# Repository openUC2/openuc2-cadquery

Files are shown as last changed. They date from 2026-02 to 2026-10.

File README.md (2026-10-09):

# openUC2 CadQuery Insert Generator (v4-style)

Programmatic generation of an **openUC2 cube insert** and **component cutouts** using **CadQuery**.

> **New: `uc2v4/` — exact parametric reconstructions of the molded V4 inserts.**
> Built from the Inventor master models (COM extraction, see
> [`extracted/README.md`](extracted/README.md)) and verified against the
> released STEP geometry:
>
> *Square-insert family* (`build_uc2v4.py`):
>
> - `uc2v4.build_master_insert()` → PRT - 2123 - MASLCK - V04 - B
>   (4 mm master-insert plate: springs, corner ribs, 82° cone opening,
>   8×45° nose grooves, self-mating screw pattern)
> - `uc2v4.build_lens_insert()` → PRT - 2027 - INSLEND43F-50 - V04
>   (17 mm lens insert: parametric `lens_diam`, pocket/seat/aperture,
>   2-turn pitch-1.7 clamping thread for the pre-screw ring)
>
> *Round-holder family* (`build_mirror_holder.py`):
>
> - `uc2v4.round_holder.build_base_holder()` → the reusable blank: the conic
>   disk whose 8 noses are the exact positives of the master insert's
>   grooves, so it seats on 45° indexing
> - `uc2v4.round_holder.build_mirror_holder()` → PRT - 2111 - MASINSMIRHOLUPP - C
>   (obround beam aperture + sandwich screw counterbores)
>
> ```bash
> uv run --with cadquery --with trimesh --with rtree --with scipy python build_uc2v4.py
> ```
> writes STEP/STL into `generated/` and prints the mesh-deviation report
> against `extracted/*.step`. Design write-up: [`DOCS-insert-v4-design.md`](DOCS-insert-v4-design.md).
> Both families are available to optikit-core as standalone T3 generators
> (`openuc2.tpl.square_insert_v4`, `openuc2.tpl.round_holder_v4`).

> **Automatic lens cartridges — `uc2v4/lens_cartridge.py`.**
> Give it a lens and a target pose measured from the cube centre; it snaps to
> the cube's notch grid (7 notches, 5.0 mm pitch, measured from
> `PRT - 1003 - CUBHLF111`), hands the residual offset and tilt to the printed
> parts, and writes the **front and back** round inserts that clamp the lens
> and drop into the molded master inserts:
>
> ```bash
> uv run --with cadquery python uc2v4/lens_cartridge.py --diameter 25.4 --thickness 3.5 --r1 51.5 --r2 -51.5 -x 3.0 -y -2.0 -z 6.1 --extension-front 1.5 --extension-back 1.5
> ```
>
> Each run also writes a `*_layout.png` schematic of the cube, the notch grid,
> the molded/printed sandwich and the lens, and engraves an identifying label
> on each outward face.
>
> `check_lens_cartridge.py` verifies a generated pair (one solid per half, no
> overlap, zero lens-to-holder collision, snug pocket, pose reproduced,
> envelope respected, **and the cone rings facing the joint** — the halves are
> not symmetric and a mirrored build passes every other check).

> **Beamsplitter / fluorescence-filter cubes — `uc2v4/beamsplitter_insert.py`.**
> A printable two-part **clamshell** (modelled on PRT-2074 / PRT-2075) that
> carries an **excitation filter**, an **emission filter** and a **45° dichroic**
> through one cube. Each optic is independently a round disc or a rectangular
> plate, with its own thickness; the excitation reflects off the dichroic to
> the sample port, the emission passes straight through:
>
> ```bash
> uv run --with cadquery python uc2v4/beamsplitter_insert.py            # the reference set
> uc2cad beamsplitter --exc-diam 25.4 --exc-thick 4 \
>                     --emi-diam 25.4 --emi-thick 4 \
>                     --dic-w 25 --dic-thick 1 --beam 18                 # or via the CLI
> ```
>
> It writes the **lower and upper** halves (STEP + STL) plus the plan JSON.
> `check_inserts.py` verifies each build (one solid per half, no overlap, every
> optic drops into its seat and lifts out of the split plane, all beam legs
> bored, pins registered). Design write-up:
> [`DOCS-beamsplitter-insert.md`](DOCS-beamsplitter-insert.md).

> **Optical-module plates — `uc2v4/opm_plates.py`.** The two 5 mm aluminium
> plates that sandwich an OPM, for **any layout**: a core rectangle such as
> `3x8` or `3x3` plus extra puzzle units on any side (`3x8+1x1@-1,0`), or a
> layout drawn as ASCII art. Built from the master `MAS - 1003 - Base plates
> Al - V04` and the released pairs (PRT-1051/1052 FLIM 488, 1053/1054, 1026/1027,
> 1047/1048): 50.0 × 50.1 mm cells with four M3 holes and a Ø38 pocket each,
> R1.5/R10.2 corners, the outward-face chamfer, tie rods at the core's corners
> (every ≤ 3 cells along long edges — the released rule), counterbores on the
> top, sleeve-nut U-slot recesses underneath, optional M37×0.5 ports:
>
> ```bash
> uv run --with cadquery --with matplotlib python build_opm_plates.py   # edit the layouts in there
> uc2cad plates --layout 3x8+1x1@-1,0 --port 1,7                       # or via the CLI
> ```
>
> Each module writes the top and base plate (STEP + STL), the assembled stack,
> a plan JSON (cells, tie rods, ports, hardware such as `8 x ISO 4762 M3x115`)
> and a layout diagram. `check_opm_plates.py` reproduces the tie rods of all five
> released plate families and matches PRT-1052 feature for feature (all 149
> cylindrical features, same 203 faces, volume −0.012 %). Design write-up:
> [`DOCS-opm-plates.md`](DOCS-opm-plates.md).

> **dvOPM camera, launch and sample parts — `uc2v4/opm_camera_adapter.py`,
> `uc2v4/opm_launch_holder.py`, `uc2v4/opm_sample_holder.py`.** The printed parts of the
> direct-view OPM on a 5x4 plate. Its detection stays in openUC2 cubes: the fold mirror and the
> reversed telecentric lens use the CAD-new modules ASS-2020 and ASS-3011 turned inside their
> cubes, and the only new detection part is the **camera adapter** — a double base-holder disc
> captured between a MASLCK and a MASINS like any printed round insert, with a bracket, a spine
> and a 4 mm plate that holds the Alvium bare board at the sensor tilt (50 deg) in the cube; the
> sensor looks through a window, four M2 hold the board from behind. The **launch holder**
> carries the RMS-threaded 4x objective, the LJ1878L1 cylinder lens (side slot + sliding key)
> and the f = 8 fibre collimator (side-slid fork clip); the arc-rail bracket's two concentric
> slots pivot it about the sheet's entry point, and the bracket hangs from the launch stage's
> slide when the slide stands above the holder. The **sample arm** is one flat slab on the
> sample stage's slide with the dish ring. Every dimension comes from the layout model in
> `openuc2-opmsimulator/opm_layout.py` (`opm_layout.json`):
>
> ```bash
> uc2cad opm-camera ../openuc2-opmsimulator/opm_layout.json      # camera adapter -> generated/opm_detection
> uc2cad opm-launch ../openuc2-opmsimulator/opm_layout.json      # holder, key, clip, bracket -> generated/opm_launch
> uc2cad opm-sample ../openuc2-opmsimulator/opm_layout.json      # sample arm + dish -> generated/opm_launch
> uv run --with cadquery python check_opm_launch_holder.py ../openuc2-opmsimulator/opm_layout.json
> ```
>
> The camera cube as built (adapter, inserts, board) is checked in openuc2-opmsimulator
> (`check_opm_detection_cubes.py`); `check_opm_launch_holder.py` verifies the thread, the seats
> and retainers, the clamp screws and that every medium's screw position lies in the bracket's
> slots. The plan JSON's `params` block also drives
> `openuc2-opmsimulator/build_opm_holder_ipt.py`, which rebuilds the launch holder as a **native
> parametric Inventor part** (35 user parameters, coil-cut RMS thread);
> `check_opm_holder_native.py <its .stp> generated/opm_launch` samples that part against the
> CadQuery reference. The beam-path solids (`generated/opm_launch/opm_beam_*.step`) come from
> `openuc2-opmsimulator/opm_beam_solids.py`. `uc2v4/opm_detection_holder.py` and
> `check_opm_detection_holder.py` are the superseded one-piece detection holder (2026-10-02).
> Pipeline write-up: `openuc2-opmsimulator/OPM_CAD_README.md`.

> **Holders for turning an optical design into cubes (2026-10-03).** The geometry behind
> optikit-core's generators (`generators/*_v4.py` there), each with a `plan_*` that checks
> without building and a `check_*.py` here that verifies the parts against what they hold:
>
> | module | holds | check |
> |---|---|---|
> | `round_clamp.py` | a cylinder body up to Ø34 mm (laser module, fibre collimator, tube) between two master inserts, one set screw | `check_round_clamp.py` |
> | `kinematic_adapter.py` | any round or rectangular optic in the ½-inch kinematic mount ZJB-0.5-3, on a plate or a wedge | `check_kinematic_adapter.py` |
> | `bolt_cradle.py` | a device by the holes in one face: an insert across the beam, or a pedestal on a plate | `check_bolt_cradle.py` |
> | `focus_cartridge.py` | a lens in a barrel that slides ±1 mm in a round clamp, set-screw lock | `check_focus_cartridge.py` |
> | `off_grid_plate.py` | a plate in the puzzle layer over a list of cells: kinematic pedestal, saddle, cradle, lens wall; docking poses | `check_off_grid_plate.py` |
> | `cube_pocket.py` | a beamsplitter cube at the centre of a cell, in the fluorescence clamshell | `check_cube_pocket.py` |
> | `slide_slot.py` | a microscope slide across the beam, stop, coverslip pocket | `check_slide_slot.py` |
> | `sample_vessel.py` | a vial or a cuvette upright across the beam, windows, light-tight cap | `check_sample_vessel.py` |
> | `cell_cover.py` | a light-tight cover over a list of cells with an interlock switch housing | `check_cell_cover.py` |
>
> `lens_cartridge.snap_joint` places every master-insert pair, and its joint plane stays within
> ±13 mm of the cube centre (`CubeInterface.joint_limit_mm`; further out the outer insert sits
> on the cube's end frames). optikit-core pins v0.6.0 and needs a new tag for these.

> **FRAME objective supports — `uc2v4/frame_objective_support.py` (2026-10-09).** The printed
> part between the FRAME's kinematic objective sled (FR110-0401) and an objective, as the
> `FRAME - 0402 / 0408 - Support objective` parts are built (measured on them): a 5.2 mm flange
> with two M2.5 lugs, a Ø25.4 boss up to the objective's shoulder, the objective's thread printed
> in the top of the bore. Thread (RMS, M25x0.75, M26x0.706, M27x0.75, C-mount, M<Ø>x<pitch>),
> height and label are parameters; `parfocal_heights` gives one height per slot so all
> objectives focus in one plane (61.4 mm above the sled for two PF-45 objectives, the CAD's 16.4
> mm supports). RMS fits as in the CAD; M25x0.75 and C-mount get screw pockets in a Ø29+ boss
> (0.6-0.8 mm wall to the pockets); M26 and wider are refused — their bore reaches the sled's
> M2.5 screws at r 16 mm, so they need a sled with the screws further out. `check_frame_objective_support.py [--cad <FRAME-0402.stp> 16.4]` checks the rules and
> samples a CAD part against the model. optikit-core's `generators/frame_objective_support.py`
> wraps it for the FRAME wizard (needs this release, v0.8.0).

> **Browser wizard — `uc2cad wizard`.** No command line needed: run it and a
> page opens where you enter the numbers for a **lens holder** or a
> **beamsplitter cube**, or click an **OPM plate layout** together on a grid,
> and download a ZIP of the files. It uses only the Python standard library
> (plus CadQuery), so it runs anywhere the generators do:
>
> ```bash
> uv run --with cadquery python -m uc2v4.wizard        # opens http://127.0.0.1:8137/
> ```

> The scripts below predate the extraction and approximate the outline from
> drawings — still useful as simple starting points, but `uc2v4/` is the
> measured reference.

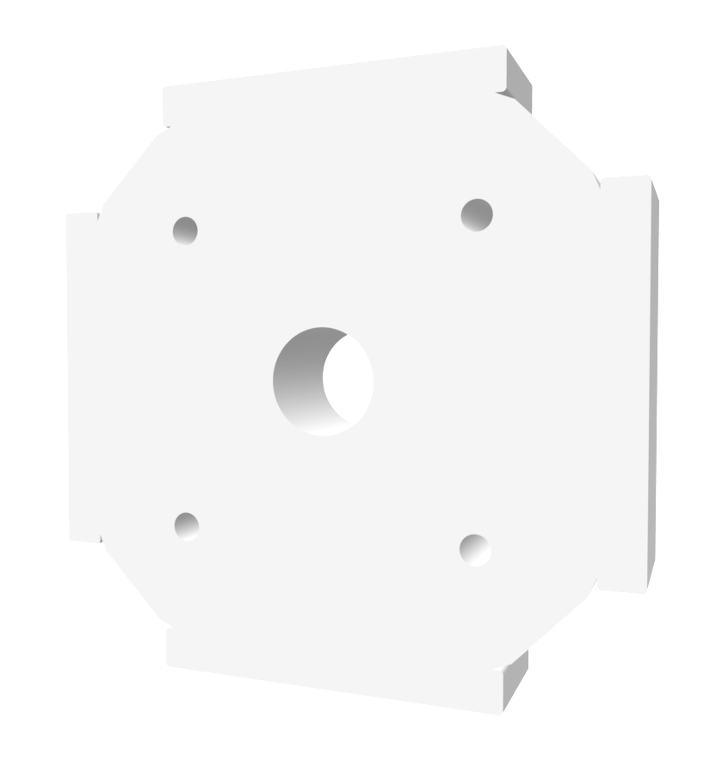
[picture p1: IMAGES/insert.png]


*Python-generated generic insert that can e.g. host a lens or something*

Goal:
- Create a reusable **insert “blank”** (outer geometry + optional tabs/wings + threaded holes).
- Create separate **component STEP cutters** (lens pockets, motor clearances, etc.).
- **Import any STEP cutter**, apply an **affine transform**, and **subtract** it from the insert to produce a printable/custom holder.

Coordinate system:
- **Optical axis = Z-axis**
- Optical axis passes through **(0, 0)** in the XY-plane
- All shapes are built around the origin by default

## Files

### 1) `uc2_component_cut_step.py`
Creates a **negative volume** (“cutter”) as a STEP file.

Typical use:
- Generate a lens pocket as a cylinder + optional seat + optional set-screw holes.
- Export as `component_cut.step` (and optionally `component_cut.stl`).

You can create multiple cutters, e.g.:
- `lens_25mm_cut.step`
- `motor_clearance_cut.step`
- `laser_mount_cut.step`

These STEP cutters are then consumed by the insert builder.

### 2) `uc2_insert_builder.py`
Creates the **insert body** and subtracts one or more imported STEP cutters.

What it generates:
- Outer insert outline (octagon-like profile from the technical drawing)
- Optional side tabs (or “wings” depending on the version you use)
- Optional center bore (or you do center bore via cutter STEP)
- Optional threaded/tapping holes
- Subtraction of imported cutters after applying affine transforms
- Exports `uc2_insert.step` and `uc2_insert.stl`

## Install

Create an environment and install CadQuery:

```bash
pip install cadquery
```

If your Python environment is already set up (e.g. `mambaforge`), install into that environment.

## Quick start

### Step 1: Create a cutter STEP (example lens pocket)

```bash
python uc2_component_cut_step.py
```

This writes:

* `component_cut.step`
* `component_cut.stl` (optional)

### Step 2: Build the insert and subtract the cutter

Edit `uc2_insert_builder.py` and add the cutter to `CUTTERS`, then run:

```bash
python uc2_insert_builder.py
```

This writes:

* `uc2_insert.step`
* `uc2_insert.stl`

## How cutters work

A cutter is any **solid STEP** you want to subtract from the insert.

Typical workflow:

1. Generate a cutter STEP in a dedicated script (preferred, reproducible)
2. Add it to `CUTTERS` list in `uc2_insert_builder.py`
3. Assign an affine transform for positioning/orientation
4. Boolean subtract (`insert.cut(cutter)`)

This supports:

* Lens holders (coaxial to optical axis)
* Motor pockets (offset + rotated)
* LED/laser holders
* Cable channels / clearance volumes
* Any imported CAD STEP solid

## Affine transforms

Each cutter can be positioned and rotated with:

* Translation: `tx, ty, tz` (mm)
* Rotation: `rx, ry, rz` (degrees, applied about origin, in order X → Y → Z)

Example: shift 2 mm in X, rotate 15° around optical axis:

```python
CUTTERS = [
    ("component_cut.step", Affine(tx=2.0, ty=0.0, tz=0.0, rx=0.0, ry=0.0, rz=15.0)),
]
```

Tip:

* If you want a lens centered on the optical axis, keep `(tx, ty) = (0, 0)`.

## Parameters you typically adjust

In `uc2_insert_builder.py`:

* `OUTER_HALF`, `SHOULDER_HALF` : insert outline
* `INSERT_THICKNESS`            : extrusion thickness
* `ADD_SIDE_TABS`, tab dimensions
* `ADD_THREAD_HOLES` and hole geometry
* `CUTTERS` list and each cutter transform

In `uc2_component_cut_step.py`:

* Lens diameter + clearance
* Seat diameter + depth
* Set screw count, diameter, radius

## License / contributions

This approach is meant to support openUC2’s open insert ecosystem:

* Generate inserts reproducibly
* Share scripts + parameters
* Allow others to remix and extend

If you create a useful cutter for a common component (lens size, motor, LED), publish it with:

* source script
* generated STEP
* a short usage snippet (recommended transform and parameters)

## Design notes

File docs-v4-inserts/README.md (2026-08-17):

# Documentation page: Module inserts (V4)

A user-facing page for
<https://docs.openuc2.com/dev/hw/module-inserts/v4/>, written for people
assembling openUC2 hardware rather than for people opening CAD.

## Contents

| file | what it is |
| --- | --- |
| `module-inserts-v4.md` | the page itself, Markdown with Docusaurus front matter |
| `img/*.png` | the figures it references |
| `make_figures.py` | regenerates figures 01–07 |

## Dropping it into the docs site

Copy `module-inserts-v4.md` to the page's location and `img/` alongside it.
The page uses relative image paths (`./img/01-overview.png`), which is what
Docusaurus expects when the images sit next to the Markdown file. If the site
keeps images in `static/img/` instead, adjust the seven paths accordingly.

## Regenerating the figures

```bash
uv run --with matplotlib python make_figures.py
```

Figures 01–07 are schematic matplotlib drawings — deliberately not to scale.
Small features (the teeth, the cone taper, the wall that traps a lens) are
exaggerated where that makes the point readable; the dimensions quoted in the
text are the real measured ones. Figure 08 is a render of an actually
generated pair of inserts, produced from the STLs that
`uc2v4/lens_cartridge.py` writes.

## Where the numbers come from

Everything quoted on the page was measured out of the Inventor originals via
the COM API rather than taken from drawings — see
[`../DOCS-insert-v4-design.md`](../DOCS-insert-v4-design.md) for the engineer-facing
version with the full derivation, and [`../extracted/README.md`](../extracted/README.md)
for the raw dumps.

Two statements on the page are *inferred* rather than directly measured, and
are worth confirming before the page goes public:

- that a sandwich is always **two** master inserts, one toothed and one
  smooth (this follows from the self-mating screw pattern and the assembly,
  but "both toothed" has not been ruled out);
- the exact phase of the tooth grid relative to the sandwich — the page only
  says the teeth are 5 mm apart, which is measured and safe, and deliberately
  avoids the finer claim.

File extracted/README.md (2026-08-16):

# Extracted ground truth (Inventor -> JSON/STEP)

Everything in this folder was pulled out of the original Autodesk Inventor
CAD through the COM automation interface by
[`PyInventor/inventor_part_probe.py`](../../PyInventor/inventor_part_probe.py):

```bash
python inventor_part_probe.py "PART.ipt" --out-dir extracted --step
```

The probe dumps, per part: iProperties, all parameters (model/user/reference,
converted to mm/deg), the ordered feature tree with per-feature parameters,
extrude/revolve **profile paths** (exact sketch curves), sketches (entities,
dimension constraints with expressions, text boxes), work features, and the
final b-rep inventory (faces with exact plane/cylinder/cone/sphere/torus
data, vertices, mass properties). `--step` additionally saves a STEP copy.

## Files

| file | role |
| --- | --- |
| `PRT_-_2027_-_INSLEND43F-50_-_V04.{json,step}` | released lens insert (derived part) |
| `PRT_-_2123_-_MASLCK_-_V04_-_B.{json,step}` | released master lock (derived part) |
| `PRT_-_2111_-_MASINSMIRHOLUPP_-_C.{json,step}` | released 45° mirror holder (derived part) |
| `MAS_-_2013_-_Square_Inserts_-_V04.json` | master model: square-insert family (5 bodies) |
| `MAS_-_2003_-_Master_Insert_-_B.json` | master model: master insert + base holder |
| `MAS_-_2007_-_Kinem_+_fixed_mirror_45°_+_90°_-_C.json` | master model: mirror holders (fixed-mirror branch rolled back) |
| `inspect_step_sections.py` | exact section-edge dump of a STEP (verification oracle) |
| `*_sections.json` | y=0 / z=0 / x=0 section edges of the released STEPs |

## What the extraction established

- The released parts are all **derived parts**: the real parametric recipe
  lives in the MAS master models (Inventor master-model workflow).
  `INSLEND43F-50` derives from body *Insert for Lenses* of MAS-2013
  (user parameters `LensDiam`, `ThreadPitch`, `LensThicknessPos/Edge/Neg`);
  `MASLCK` derives from body *Master Insert* of MAS-2003
  (`InsertDiam`, `OffsetDiameterBaseHolder`); `MASINSMIRHOLUPP` derives from
  MAS-2007, which in turn derives its *Base holder* from MAS-2003 — so the
  round-holder interface is one recipe shared by the whole round family.
- A master model can have branches **rolled back** behind its end-of-part
  marker: MAS-2007's live bodies are the kinematic-mount variant, while the
  fixed-mirror body the released part derives from is not currently
  computed. When the master and the released b-rep disagree, the released
  part wins.
- The common square-insert interface is parametrized in the masters as
  `Grid - 0.6` (envelope 49.4), `CubeClearWidth - 0.1|0.2` (shoulder
  33.9|33.8), `CubeClearDiagonalV04 - 0.2|0.4` (corner flats 53.54|53.34)
  and `OuterChamfer` (0.4).
- The Inventor-written STEP files silently break OpenCascade booleans
  (tolerance abuse) - use mesh-domain comparison, and expect a few open
  triangles in their tessellation (e.g. around the MASLCK pilot-hole
  relief cones).

The parametric CadQuery reconstruction that consumes these numbers is the
[`uc2v4`](../uc2v4/) package; `python build_uc2v4.py` rebuilds and
re-verifies both parts against the STEPs in here.

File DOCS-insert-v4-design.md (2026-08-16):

# openUC2 V4 module inserts — design description & measured interface spec

*Prepared for docs.openuc2.com (extends https://docs.openuc2.com/dev/hw/module-inserts/v4/).
Every number below was extracted from the Inventor master models through the
COM API and cross-checked against exact STEP sections of the released,
injection-molded parts. Sources: `MAS - 2003 - Master Insert - B.ipt`,
`MAS - 2013 - Square Inserts - V04.ipt`, released parts PRT-2123 (MASLCK)
and PRT-2027 (INSLEND43F-50).*

## 1. System concept

The openUC2 toolbox is built on a **50 mm cube grid** (`Grid = 50 mm`).
Hollow injection-molded cubes snap onto baseplates; **square inserts** slide
into the cubes and carry the optics. Because cubes, baseplates and the
generic inserts are injection molded, the mechanical interface is highly
reproducible — every custom holder only has to match the insert interface,
not the cube itself. Custom holders are then either 3D-printed inner parts
clamped by molded inserts, or (with the parametric CAD below) complete
insert-shaped parts.

## 2. The square-insert interface (common to all V4 inserts)

Top view: a square envelope with stepped corners and four flexure springs.

| feature | value | Inventor parameter |
| --- | --- | --- |
| envelope (square) | 49.4 × 49.4 mm | `Grid − 0.6` |
| shoulder width (slides in the cube tracks) | 33.9 mm (lens inserts) / 33.8 mm (master insert) | `CubeClearWidth − 0.1 / − 0.2` |
| 45° corner flats, across corners | 53.54 mm / 53.34 mm | `CubeClearDiagonalV04 − 0.2 / − 0.4` |
| corner-edge fillet | r 0.4 / r 0.5 | — |
| outer chamfer on all top/bottom outline edges | 0.4 × 45° | `OuterChamfer` |
| plate thickness | 4.0 mm (master insert), 17 mm (lens insert), variant-specific | `HightMasterInsert`, `d167`, … |

**Corner steps.** Each corner is cut back to the 45° flat (clears the cube's
corner posts) with a ledge back to the shoulder plane. On the master insert
the two ledges on the ±X sides additionally carry a **raised rib** (crest
0.8586 mm proud of the ledge, flat over z ±0.14, 45° flanks ending at
z ±1.0, plan end rounded r 0.5): it rides in the center groove of the cube
track and gives the 4 mm plate its lateral seating.

**Flexure springs.** Two per side on two opposite sides (±Y), molded into
the plate by a slot cut. Each spring is a ~7°-tapered finger whose tip
carries a rounded hook nose (r 0.5). In the **sliding** variants the nose
tip stays ≈ 0.1 mm below the 49.4 envelope: the springs only preload the
insert against the cube track so it can be repositioned continuously along
the optical axis (focusing). The **locking** variants add a tongue bump
(a suppressed feature pair in the master model) that engages one of the
**7 notches** molded into each cube side, giving discrete, repeatable
positions perpendicular to the optical axis.

## 3. The master insert (MAS-2003 → PRT-2100 MASINS / PRT-2123 MASLCK)

A 4 mm plate on the interface above, with a conic center opening:

- **Cone**: Ø40.0 at the bottom face → Ø38.876 at the top face
  (`InsertDiam = 40`, wall at **82°** to the face), both rims chamfered
  0.2 mm equal-leg.
- **8 nose grooves** ("teeth") every **45°** (phase 22.5°): each groove is
  the full revolution of a Ø1.6 cylinder about an axis parallel to the cone
  wall, inset 0.3 mm perpendicular from it, ending in an **R 1.3 spherical
  pocket** at the top face (the visible dimples). Groove rims are blended
  r 0.5.
- **Base holder** (the round carrier all round inserts derive from): the
  complementary conic disk, offset **+0.05 mm** (`OffsetDiameterBaseHolder`)
  for snap interference, with 8 matching noses — see §5. Result: any round
  insert clicks into the master insert in **45° indexed orientations**, or is
  held purely by friction between the teeth.
- **Self-mating screw pattern**: at (±21.4, ±13.6) each half carries one
  diagonal pair of Ø1.9 thread-forming pilot holes (3.5 deep from the top,
  45° relief cone breaking through the bottom) and one diagonal pair of
  Ø2.8 clearance holes with Ø5.0 × 2.0 head counterbores. Two *identical*
  halves screwed face-to-face therefore clamp an optic between them —
  one mold, no left/right parts (screws: TP 2.5 × 6 Torx).

## 4. The square lens insert (MAS-2013 → PRT-2027 INSLEND family)

A 17 mm tall block on the same interface whose interior is the lens cavity
(all Ø parametric in `LensDiam`, INSLEND43F-50 shown):

| z (mid-plane = 0) | feature |
| --- | --- |
| +8.5 … +8.1 | top face, 0.4 chamfer into the bore |
| +8.1 … +2.9 | internal clamping thread: root Ø`LensDiam+2.2` (45.2), crest Ø`LensDiam+0.8` (43.8), **pitch 1.7 mm** (`ThreadPitch`), 2 turns, 45° trapezoidal flanks |
| +2.9 … +2.0 | 45° lead-in cone |
| +2.0 … −6.3 | lens pocket Ø`LensDiam+0.4` (43.4) |
| −6.3 | lens seat shoulder |
| −6.7 … −8.1 | clear aperture Ø`LensDiam−4` (39.0), chamfered both ends |

The **knurled pre-screw ring** (Ø49.6 = `LensDiam+6.6`, height
`3·ThreadPitch+0.8`, 12-flute knurl) screws into the thread and clamps the
lens onto the seat — lens exchange without tools, preload without glue.
The naming encodes the optic: `INSLEND43F-50` = insert, lens end,
Ø43 mm, f = 50 mm.

## 5. The round base holder (MAS-2003 body *Base holder*)

Everything round that goes into a cube — mirror holders, laser holders, the
MASINS\* family — is the **base holder** disk plus its own pocketing. It is
the negative counterpart of the master insert's cone and grooves:

| feature | value |
| --- | --- |
| widest radius (at the band's bottom plane) | 20.0505 mm = Ø40/2 + 0.05/cos 8° |
| wall | **82°** to the face (8° from the axis), same cone as the master insert |
| interface band height | 4.0 mm — exactly the master insert's thickness |
| blend to the top face | r 0.35 (top face radius 19.1841 mm) |
| noses | 8 at 22.5° + k·45°, Ø1.6 |

`OffsetDiameterBaseHolder = 0.05 mm` is a **face** offset, not a radial one,
so on the 82° wall it becomes 0.050491 mm radially — that is the snap
interference against the master insert's cone.

**The nose is the groove.** The nose and the master insert's groove are
generated from the *same* line: an axis parallel to the cone wall, inset
0.3 mm perpendicular to it, swept with the same Ø1.6 circle. The master
insert subtracts it (ending in an R1.3 spherical pocket), the base holder
adds it (ending in a cap that is a 1.0 mm circle revolved about the axis
0.1 mm off-center, blended to the shank with r 0.2). The nose axis bottom is
placed exactly so its tilted flat end is tangent to the band's bottom plane,
which is what lets the tooth bottom out cleanly. Both parts therefore mate
along a nominal line contact and index every 45°.

## 6. The 45° mirror holder (MAS-2007 → PRT-2111 MASINSMIRHOLUPP)

The base holder plus a 0.4 mm skirt below the band (so the disk stands
proud of the master insert), and:

- an **obround beam aperture**, lobes Ø10 at (6, ±2), i.e. 10 × 14 mm
  clear, sitting 6 mm off the optical axis — a 45° fold mirror's footprint
  is an ellipse, so the opening is elongated and offset on the reflected
  side. Chamfered 0.4 × 45° at both faces.
- **two sandwich screws** at (−7.2, ±13.6): Ø2.9 clearance with Ø5.0 × 2.0
  counterbores. Upper and lower holder halves screw together and clamp the
  mirror (Ø24 × 3 mm on a Ø22 adhesive pad, per `MirrorDiam` /
  `AdhesivePadDiam` in the master).

Note the master model's fixed-mirror branch is **rolled back** (its live
bodies are the kinematic-mount variant), so the released part's b-rep — not
the master's current feature state — is the authority for these numbers.

## 7. The cube's discrete grid (PRT-1003 CUBHLF111)

Measured off the molded cube half:

| feature | value |
| --- | --- |
| track walls (the insert's shoulder slides between them) | x = ±17.03 / −17.06, gap 34.09 mm (`CubeClearWidth` 34.0) |
| **notches** | **7, pitch exactly 5.0 mm, at −15, −10, −5, 0, +5, +10, +15 mm from the cube centre** |
| notch width along the travel axis | 1.88 mm |
| notch band height | 3.44 mm |

Only one pair of opposite walls is notched — the other pair is a single
unbroken face, which is why an insert grips discretely on one axis and slides
freely on the other.

**Phase of the grid.** The locking tongue (MAS-2003 `Skizze37 --- for tongue`,
suppressed in the sliding variants) is a triangular bump on the insert's
shoulder wall, profile spanning z = −2…+2 with its tip at **z = 0** — i.e.
centred on the master insert's own mid-plane. So a notch fixes *the notched
insert's mid-plane*, and in a two-insert sandwich the joint plane lands half
an insert (2 mm) to one side of the notch. Reachable joint planes are
therefore 5k ± 2 mm, and the printed adapter has to absorb up to ±2 mm of
axial residual — which it comfortably can inside an 8 mm sandwich.

## 8. Automatic lens-cartridge generation

`uc2v4/lens_cartridge.py` closes the loop from an optical prescription to two
printable files. Given a lens (diameter, centre thickness, R1, R2) and a
target pose (x, y, z, rx, ry, rz) measured **from the cube centre**, it:

1. snaps z onto the notch grid above, choosing which half carries the tongue
   so the lens lands as close as possible (`notched_half="auto"`);
2. hands the entire remainder — the full transverse offset, the residual
   axial offset, and the tilt — to the printed pair;
3. cuts the lens cavity as a **true offset negative of the lens** (the sphere
   offset is exact in the signed convention: R1 → R1 + c, R2 → R2 − c, with
   the vertices moving apart by c), so a curved surface seats on its whole
   face rather than on a flat shoulder;
4. bores the clear aperture along the lens axis and adds keyed alignment pins,
   auto-clocked to miss the pocket;
5. emits `*_front.step/.stl`, `*_back.step/.stl`, a `*_plan.json` recording the
   notch index, the joint plane, the residual offsets and any warnings, and a
   `*_layout.png` schematic (`uc2v4/cartridge_plot.py`) showing the notch grid,
   the chosen notch, the molded/printed sandwich and the lens in place.

Both halves carry the full base-holder profile from §5, so they drop into the
molded master inserts and index every 45°.

**Which way round the halves go.** The two master inserts mate *flipped* —
their self-mating screw pattern (§3) only works if one is rotated 180° about
an in-plane axis. Rotating a cone that is wide at its bottom face about such
an axis leaves it wide at the same plane, so **both cones end up wide on the
joint and narrowing outward**. Each printed half is therefore dropped into
its master insert from the joint side and trapped when the sandwich is
screwed shut: the wide Ø40 ring faces *inward*. Consequences that follow
from this and are easy to get backwards:

- the nose caps sit on the **outward** end of each half;
- any axial extension ("skirt / support") can only be added on that same
  outward end — inward is the other half, and the seating cone must not be
  touched;
- the alignment pins straddle the joint plane, boss on one half and socket
  on the other (`pin_boss_on`).

`check_lens_cartridge.py` asserts the orientation explicitly — measuring the
half's radius near the joint against its radius near the outward face —
because a mirrored build still satisfies every other check.

Each half is engraved on its outward face with an identifying label
(`D25.4 N4 F` by default: diameter, notch index, front/back). The text runs
tangentially in the annulus between bore and rim, and shrinks to fit.

**Depth is sized automatically.** `extension_front_mm` / `extension_back_mm`
default to `None`, which sizes each half's outward extension to exactly what
is needed to bury the lens with `min_wall_mm` behind it, rounded up to
0.1 mm — no more guessing a value that "works but is thicker than necessary".

**Getting the lens in.** A lens whose full-diameter rim straddles the joint
plane can simply be laid into one half and capped by the other: at the joint
the pocket is already the full lens diameter. But when the rim ends up wholly
inside one half — which happens easily, since the reachable joint planes are
only 5k ± 2 mm — that half becomes a **closed pocket with a mouth narrower
than the lens**, and the assembly is physically impossible. The generator
detects this from the rim's z-extent and responds with:

- the seat half **bored open to the full lens diameter** from its rim face
  right through to the joint plane, so the lens drops straight in;
- the other half carrying a **stamp**: an annular plunger, inner Ø the clear
  aperture, that reaches across the joint and presses the lens onto its seat.
  Its contact face is cut by the lens cavity displaced `2 × clearance +
  stamp_preload_mm` away from the joint — the lens comes to rest one
  clearance down on its seat, so the stamp must reach twice that to touch it.

Both the bore and the stamp are built in the lens' own frame and then posed,
so a tilted lens gets a channel along *its* axis; clipping a tilted corridor
with a z-slab leaves wedges of material exactly where the lens must travel.
`check_lens_cartridge.py` verifies assembly directly by sliding the nominal
lens along its axis out through the joint and checking that no holder
material obstructs it.

`check_lens_cartridge.py` verifies each generated pair: one solid per half,
no half-to-half overlap, **zero collision between the nominal lens and the
holder**, a pocket snug enough that an oversized lens interferes, the lens
reference point landing on the requested cube coordinate, and both halves
staying inside the base-holder envelope.

## 9. Parametric CAD layer (this repo + optikit-core)

- `uc2v4/` (CadQuery). Square-insert family: `build_master_insert()` and
  `build_lens_insert()` reproduce PRT-2123 / PRT-2027; round family:
  `build_base_holder()` (the reusable blank) and `build_mirror_holder()`
  reproduce the PRT-2111 lineage. Verified against the released STEPs by
  `build_uc2v4.py` and `build_mirror_holder.py`. Everything is a dataclass
  parameter: grid, shoulder, thickness, springs on/off, notch/nose count and
  phase, hole pattern, `lens_diam`, thread, aperture shape…
- `optikit-core` T3 generators, so optikit can emit correct-interface
  holders directly into cube slots:
  `openuc2.tpl.square_insert_v4` (lens block) and
  `openuc2.tpl.round_holder_v4` (round base holder + parametric aperture).

Measured agreement with the Inventor originals (mesh deviation, both
directions, excluding the engraved labels):

| part | volume Δ | p99 | max |
| --- | --- | --- | --- |
| PRT-2123 MASLCK | +0.14 % | 0.05–0.10 mm | 0.35 mm |
| PRT-2027 INSLEND43F-50 | +0.51 % | 0.18 mm | 0.74 mm |
| PRT-2111 MASINSMIRHOLUPP | +0.82 % | 0.045 mm | 0.05 mm |

(the volume deltas are essentially the omitted engraving: for PRT-2111,
+39.1 mm³ against 36.0 mm³ of engraved recess.)

### Deliberate omissions of the CAD reconstruction

- engraved label text (0.2 mm deep top-face labels on the master insert,
  0.7 mm deep labels on the lens insert and the mirror holder),
- r 0.5 blend fillets around the notch grooves and the 0.2 chamfer wrap at
  their rims; the r 0.1 nose-root fillet on the base holder (this is the
  entire 0.05 mm residual on PRT-2111),
- thread run-out feathering at the two coil ends,
- sub-0.1 mm blend nuances where the corner rib meets the side face.

None of these affect the cube-facing interface or the optic seating.

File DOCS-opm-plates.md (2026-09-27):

# openUC2 V4 optical-module (OPM) plates — top and base plate for any layout

*Parametric generator for the two 5 mm aluminium plates that sandwich an
optical module. Reverse-engineered over COM from the master
`MAS - 1003 - Base plates Al - V04` and the released pairs PRT-1051/1052
(3×8+1×1, the FLIM 488 module), PRT-1053/1054 (3×7+1×1), PRT-1026/1027 (3×6),
PRT-1047/1048 (3×3+1×2) and PRT-1045 (3×3); dumps and STEP ground truth in
[`extracted/plates/`](extracted/plates/).*

Source: [`uc2v4/opm_plates.py`](uc2v4/opm_plates.py). Editable layouts:
[`build_opm_plates.py`](build_opm_plates.py). Verified by
[`check_opm_plates.py`](check_opm_plates.py).

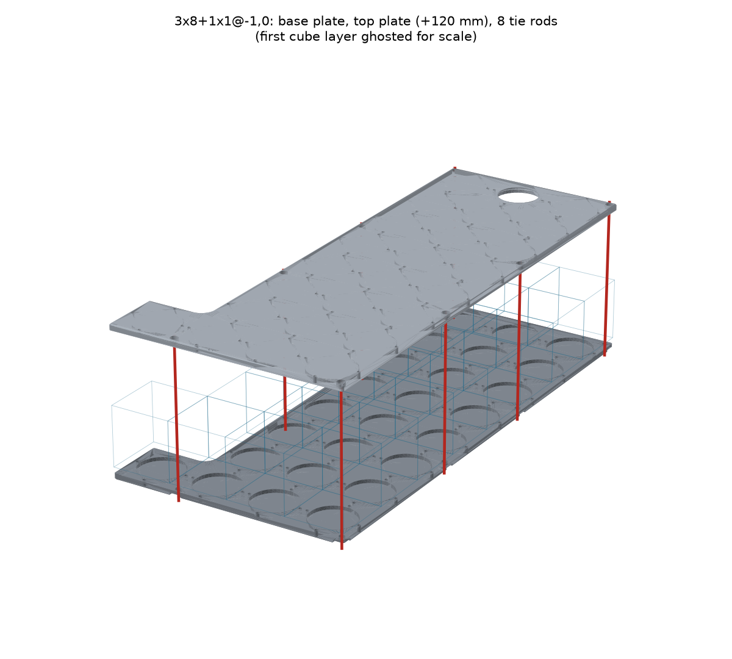
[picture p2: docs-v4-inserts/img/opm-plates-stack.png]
The FLIM 488 plate pair in its stack position


## 1. What an OPM is

An optical module is a block of 50 mm cubes clamped between a **base plate**
and a **top plate**. Every cube layer stands on a 5 mm **puzzle layer**
(PUZ11 pieces, one per cell, screwed to the plates' M3 holes), and M3 **tie
rods** run through the cube corners from the top plate to sleeve nuts under
the base plate:

```
 top plate      5 mm   ← ISO 4762 M3 heads in counterbores, optional port
 puzzle layer   5 mm
 cube layer 2  50 mm
 puzzle layer   5 mm
 cube layer 1  50 mm   (cube centres at z = 0)
 puzzle layer   5 mm
 base plate     5 mm   ← M3×8 sleeve nuts in recesses
```

One cube layer plus its puzzle layer is 55 mm, so for *L* layers the top plate
sits `55·L + 10` mm above the base plate (120 mm for the two-layer FLIM module)
and the tie rods are ISO 4762 **M3 × (55·L + 5)** — M3×115 for two layers,
exactly the hardware of `OPM - 0004 - FLIM 488`.

## 2. Describing a layout

Cells sit on a grid; cell `(c, r)` is column *c* (x) and row *r* (y), and cell
`(0, 0)` is the first cell of the **core rectangle**. Extra **puzzle units** can
hang off any side, including at negative indices.

| layout | meaning |
| --- | --- |
| `"3x3"` | 3 columns × 3 rows |
| `"3x8+1x1@-1,0"` | 3×8 core plus one extra unit left of cell (0,0) — PRT-1051/1052 |
| `"3x3@0,3+1x2@1,1"` | 3×3 core in rows 3–5 with a 1×2 leg under the middle column — PRT-1047/1048 |
| `"3x6-1x1@2,5"` | `-WxH@c,r` removes a block (here: a corner cell) |

`+WxH@c,r` adds a *W*×*H* block whose lower-left cell is `(c, r)`. Or draw it,
top line = far end, as seen from above:

```
.#P#.        #  core cube cell (carries the tie rods)
+###+        +  extra puzzle unit (no rods)
.###.        P  core cell with an M37 port in the top plate (p: extra cell)
..+..        .  empty
```

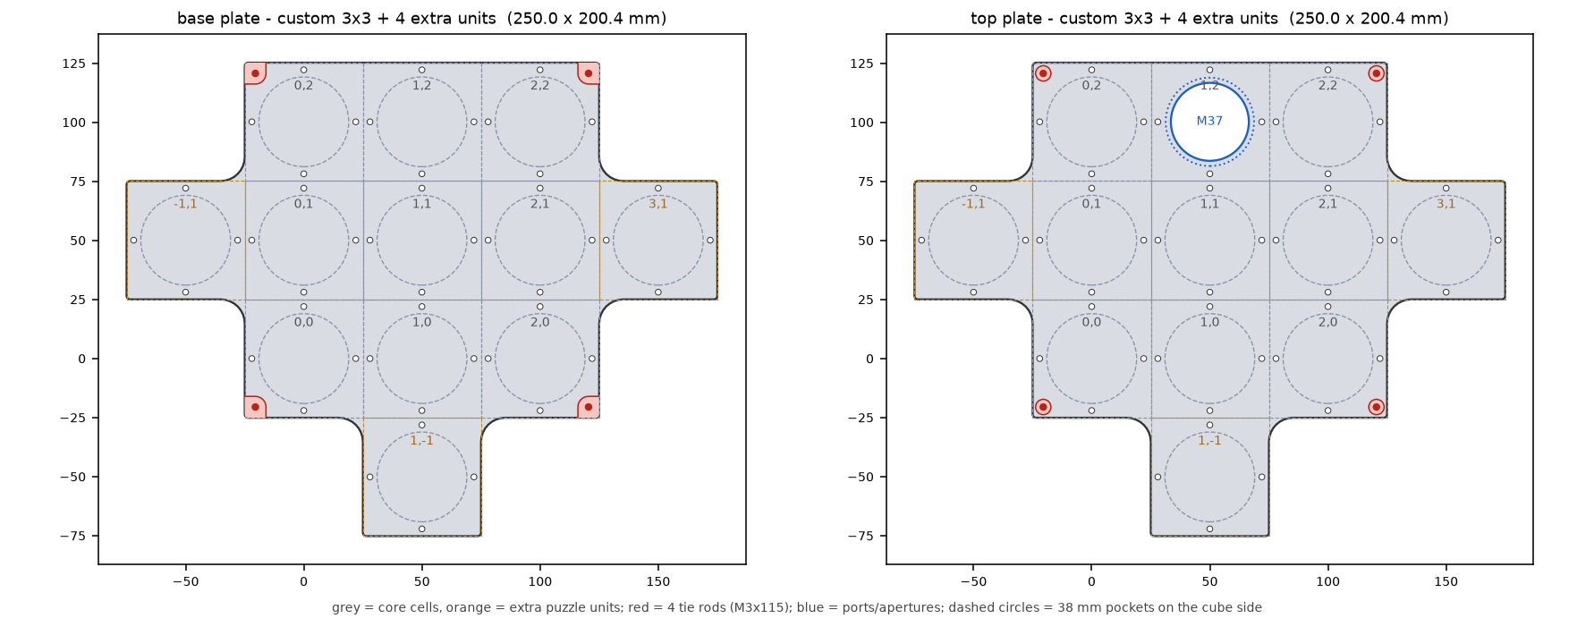
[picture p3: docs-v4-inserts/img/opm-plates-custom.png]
A free-form layout: 3×3 core, four extra units, one port


Layouts are validated: the cells must form **one piece** joined along edges —
two cells that touch only at a corner would pinch the plate to a point and are
refused, as are ports, apertures or rods placed on cells that are not there.
Enclosed holes (a ring of cells) are allowed.

**Pitch.** The master patterns columns at `Grid` = **50.0 mm** and rows at
`Grid + 0.1` = **50.1 mm**, and every current plate follows it (the older
PRT-1045 uses 50.0 both ways). It is a parameter, `pitch_mm=(50.0, 50.1)`.

## 3. What each plate carries

Both plates are modelled in the same frame as the Inventor parts — cell
(0, 0) centred on the origin, plate at z −35…−30 — and the top plate is
*translated*, not flipped, into place. So the cube side is z = −30 on the base
plate and z = −35 on the top plate.

| feature | value | source |
| --- | --- | --- |
| cell square | 50.0 × 50.1 mm, 5 mm thick; the outline is the union of the cells | MAS-1003 `Extrusion33`, `Rectangular Pattern1` |
| M3 holes | 4 per cell at (±22, 0), (0, ±22); M3×0.5-6H tapped through (modelled at the 2.46 minor Ø) | `Hole7` + `Circular Pattern9` |
| cell pocket | Ø38 × 3 mm on the cube side, every cell except a port cell | `Hole13/16` + `Rectangular Pattern4` |
| vertical edges | R1.5 at outside corners, R10.2 at inside corners (a Ø20 cutter) | `Fillet10`, `Fillet11/12` |
| outward face | 1 mm × 45° chamfer round the outline (and the base recesses) | `Chamfer16` |
| tie rods | at ±20.5 mm from a cell centre — the PUZ11 corner holes | `Hole10/13`, `Mirror3/4` |
| top plate, per rod | Ø3.4 through + Ø6.5 × 3.1 counterbore from the outer face | `Hole13`, `Extrusion15` |
| base plate, per rod | Ø4.5 through + R4.5 × 2.4 recess from below, run out as a **U-slot** to any plate edge it would otherwise graze (the rod is only 4.5 mm from a free edge); a corner rod gets a notch | `Hole10`, `Extrusion12/15` |
| M37 port (optional) | thread M37×0.5 from the cube side (2.73 deep at the 36.46 minor Ø), 45° step to a Ø37.4 × 1 relief, Ø33 aperture through a 0.8 mm lip — holds an optic with a M37×0.5 retaining ring | `Revolution1`, `Hole20` |

Also available: **plain apertures** (`Aperture(cell, d_mm, chamfer_mm)` — e.g.
the Ø35 + 1 mm chamfer port of PRT-1045/1047) and **custom holes**
(`CustomHole(d_mm, cell, offset_mm, depth_mm, face)`, through or blind from
either face).

## 4. Where the tie rods go

The rods clamp the stack, so they sit at the **outside corners of the core
cells**, plus intermediate rods along long edges so that **no more than three
cells** separate two rods. An intermediate rod goes into the cell on the side
of the nearer edge end; the exact middle of an even edge goes to the higher
row/column, so opposite edges stay mirror images. Extra puzzle units get no
rods. This one rule reproduces every released plate:

| part | layout | rods |
| --- | --- | --- |
| PRT-1045 | 3×3 | 4 corners |
| PRT-1026/1027 | 3×6 | corners + one pair at the middle (rows 2 \| 3) |
| PRT-1053/1054 | 3×7+1×1 | corners + pairs at rows 1 \| 2 and 4 \| 5 |
| PRT-1051/1052 | 3×8+1×1 | corners + pairs at rows 2 \| 3 and 4 \| 5 |
| PRT-1047/1048 | 3×3+1×2 | `tie_rods="outline"`: the leg's far corners too |

`tie_rods` is `"auto"` (core corners), `"outline"` (every outside corner of
the whole layout), `"none"`, or an explicit list such as
`(TieRod((0, 0), "sw"), TieRod((2, 0), "se"))`. Rods must pass through cubes
(or at least puzzle pieces) in every layer — the layout diagram shows them in
red, so check that against your module.

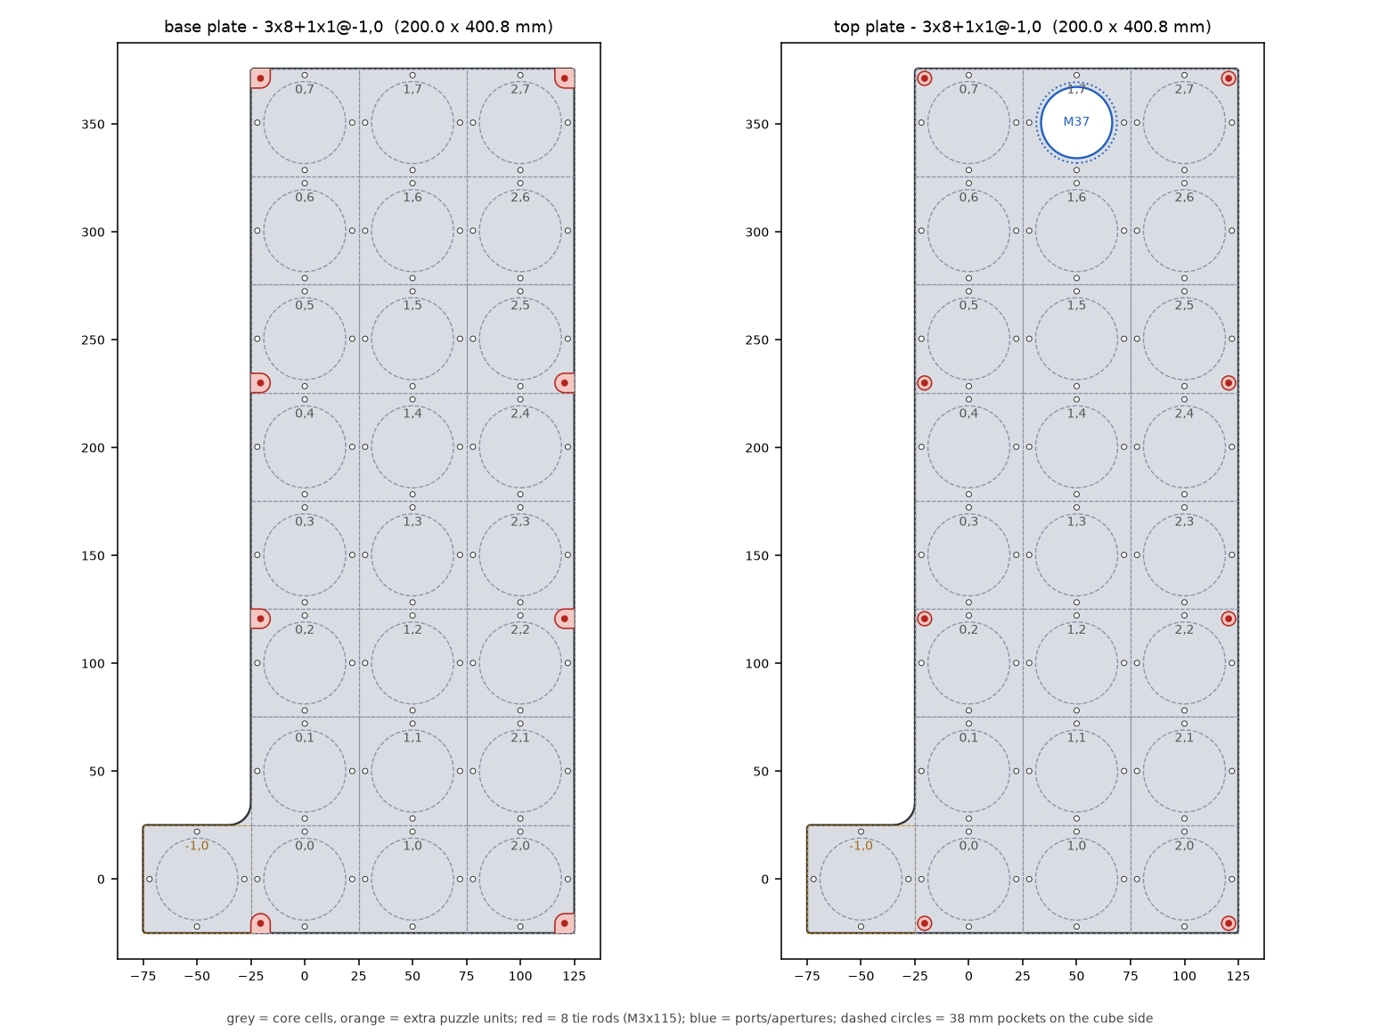
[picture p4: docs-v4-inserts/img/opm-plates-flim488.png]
Plan view of the FLIM 488 pair as generated


## 5. Using it

**Python** — define layouts in [`build_opm_plates.py`](build_opm_plates.py) and run
it, or directly:

```python
from uc2v4.opm_plates import OpmPlateSpec, PlateLayout, Port, generate

spec = OpmPlateSpec(layout=PlateLayout.parse("3x8+1x1@-1,0"),
                    layers=2, ports=(Port(cell=(1, 7)),))
plan = generate(spec, out_dir="generated/opm_plates/flim_488")
```

`generate` writes `*_top.step/.stl`, `*_base.step/.stl`, `*_stack.step` (both
plates in place), `*_plan.json` (cells and centres, tie rods, ports, pockets,
hardware list, mass) and `*_layout.png`. `plan_opm_plates(spec)` gives the plan
without building; `build_opm_plates(spec)` returns the two CadQuery solids.

**Command line**

```bash
uc2cad plates --layout 3x8+1x1@-1,0 --port 1,7
uc2cad plates --layout "3x3@0,3+1x2@1,1" --tie-rods outline --aperture 1,5:35:1
uc2cad plates --ascii-file my_module.txt --layers 1 --m3-hole 3.2
uc2cad plates --layout 4x4 --plan-only        # print the plan, build nothing
```

**Browser** — `uc2cad wizard`, tab *OPM plates*: click the cells on a grid
(core, extra unit, port), set the layers, and download a ZIP of all files with
a preview of the layout.

**optikit** — `build_parts(params)` returns `{"top": …, "base": …}` from
JSON-able parameters (`layout` as a spec string, ASCII or cell list, `layers`,
`ports`, `apertures`, `holes`, `tie_rods`, `pockets`, `pitch_mm`,
`m3_hole_d_mm`); `spec_from_dict` documents the keys. This is the surface the
OPM designer in optikit-v2 should call, in place of
`optikit-core/generators/plate_nxm.py`.

## 6. Verification

`check_opm_plates.py` (9 checks) asserts:

- the rod rule against all five released families (table above; worst 0.05 mm);
- for a plain 3×3, the released L, a 3×3 with extras on all four sides plus a
  port and an aperture, a ring with an enclosed hole, and a single one-layer
  cell: one valid solid per plate, extent = cells × pitch, 4 M3 holes per
  cell, a pocket per cell that takes a Ø37.8 disc, rods that pass straight
  through both plates with the M3 head and the sleeve nut seating, the port's
  aperture, lip and thread, apertures clear, and a chamfer on the outward face
  only;
- against the released STEPs (when `extracted/plates/` is present): the top
  plate matches **PRT-1052** in all 149 cylindrical features and has the same
  203 faces, volume −0.012 %, surface deviation p99 0.0005 mm / max 0.10 mm;
  the base plate (with PRT-1051's module-specific holes added as custom
  holes) matches **PRT-1051** in every feature but its 2.1 mm slots;
- the refusals (islands, corner contacts, unpositioned extra blocks, features
  on missing cells, zero layers, an oversize port).

```bash
uv run --with cadquery python check_opm_plates.py
uv run --with cadquery --with trimesh --with rtree --with scipy python check_opm_plates.py
```

## 7. Deliberate simplifications

- **Module-specific base-plate features are not generated.** PRT-1051, -1053
  and -1027 also carry four Ø10 × 2.4 pockets and a set of 2.1 mm-wide slots
  on the underside at a fixed distance from the far edge (and PRT-1051/1053
  two Ø4.2/Ø3.4 holes in row 1); PRT-1047/1048 have their own (Ø8.4 holes,
  Ø16.2 × 0.5 recesses, Ø20 pockets). Add what a module needs with
  `CustomHole`s.
- **Extra units use the grid pitch.** The released 3×8+1×1 places its extra
  cell at 50.1 mm in x (the grid says 50.0), i.e. 0.1 mm further out; within
  the drawing's ⌖0.1 tolerance, and the only deviation in the PRT-1052 match.
- Tapped holes are plain minor-diameter bores (threads are a drawing note:
  M3×0.5-6H, M37×0.5-5H). For printed plates use `m3_hole_d_mm=3.2`.
- Older variants' details (counterbore chamfers of PRT-1045/1047, the Ø35 port
  instead of the M37 thread) are available as options, not defaults.

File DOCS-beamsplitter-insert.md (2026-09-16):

# openUC2 V4 beamsplitter / fluorescence-filter insert

*Parametric generator for the kinematic beamsplitter cube — the printable
clamshell that carries an excitation filter, an emission filter and a 45°
dichroic through one 50 mm cell. Modelled on the released reference pair
`PRT - 2074 / PRT - 2075` (`MAS - 2063 - Insert splitter plus 2 filters as
discs`), probed from Inventor over COM (see [`extracted/`](extracted/)).*

Source: [`uc2v4/beamsplitter_insert.py`](uc2v4/beamsplitter_insert.py).
Verified by [`check_inserts.py`](check_inserts.py).

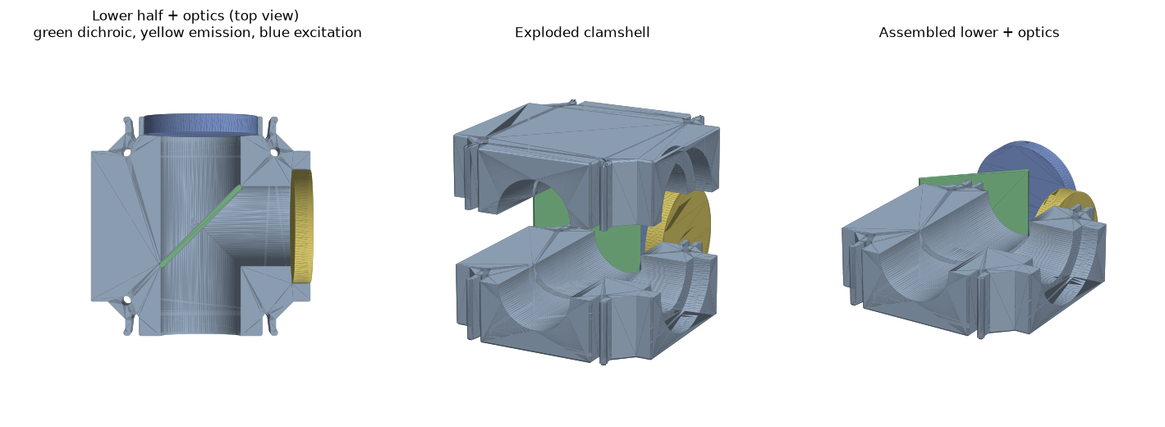
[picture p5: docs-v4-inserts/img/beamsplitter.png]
The beamsplitter clamshell with its three optics


## 1. What it is

A fluorescence filter cube routes three beams through one cell:

```
   excitation  >───┐
                   │  dichroic, 45°
       sample  ↕───┼───↕  emission >
                   │
```

The **excitation** light comes in a side face, reflects off the 45° **dichroic**
down to the **sample** (objective), and the returning fluorescence passes
*through* the dichroic and out to the **emission** filter (camera).

Because a Ø25 dichroic turned 45° is ~18 mm deep and each filter wants its own
seat, the whole thing is a tall square insert that fills the cell and **splits
at its mid-plane** into a **lower** and an **upper** printed half. You open it
like a book, drop the three optics into their seats, close it and pin it — every
seat straddles the split plane, so that plane is what gives you access. This is
exactly the reference design; only the numbers are now parametric.

## 2. Coordinate frame and ports

| axis | role |
| --- | --- |
| **+X** | excitation port (from the light source) |
| **+Y** | emission port (to the camera) |
| **−Y** | sample port (objective) — a plain open bore |
| **+Z** | the stack / split / pin axis (how the clamshell opens) |

With the default 45° dichroic the excitation (+X in) reflects to the sample
(−Y). `handedness = -1` mirrors that (excitation → +Y). Any `fold_deg` in
`[0, 90)` is allowed; `0` stands the dichroic square across the beam (a plain
plate beamsplitter).

## 3. Parameters

Each optic is a `Plate` (shared with [`fold_insert.py`](uc2v4/fold_insert.py)):
**round** (`diameter_mm`) or **rectangular** (`outline_mm = (width, height)`,
where *width* is horizontal and *height* is along the split axis), each with
its own `thickness_mm`. Any of the three may be `None` — the two filter ports
then become plain bores, and a `None` dichroic leaves the centre empty.

```python
from uc2v4 import BeamsplitterParams, build_beamsplitter_insert
from uc2v4 import Plate   # re-exported from fold_insert

params = BeamsplitterParams(
    excitation=Plate(thickness_mm=4.0, diameter_mm=25.4),   # round
    emission=Plate(thickness_mm=4.0, diameter_mm=25.4),     # round
    dichroic=Plate(thickness_mm=1.0, outline_mm=(25, 25)),  # square, at 45°
    beam_diameter_mm=20.0,
)
lower, upper = build_beamsplitter_insert(params)
```

| parameter | default | meaning |
| --- | --- | --- |
| `excitation`, `emission`, `dichroic` | `None` | the three optics (round or rectangular `Plate`) |
| `fold_deg` | `45` | dichroic tilt; `0` = square across the beam |
| `handedness` | `1` | reflect excitation to −Y (`1`) or +Y (`-1`) |
| `thickness_mm` | auto | total stack height; auto-sizes to the tallest optic + walls |
| `beam_diameter_mm` | `20` | clear beam bore; each filter aperture is this wide |
| `retaining_lip_mm` | `1.4` | radial lip that keeps a disc in its seat |
| `fit_clearance_mm` | `0.2` | gap all round each optic |
| `pin_style` | `"dowel"` | `"dowel"` (bought pin, through-hole both halves) or `"printed"` (boss + socket) |
| `pin_positions` | 3 corners | `(±16.8, ±16.8)`, three of four corners as in the reference |

The generator **auto-sizes the stack height** to the tallest optic plus a wall
top and bottom, and **refuses** the impossible with a clear message: a dichroic
too tall for a forced-thin insert, a dichroic wider than the shoulder, a
`fold_deg` of 90°. If a beam bore is so wide it leaves less than the retaining
lip on a filter, it emits a warning rather than failing.

## 4. How the optics are held

- **Filters (±X, +Y).** Each seats in a pocket that opens at the outer face and
  stops at a lip; the beam aperture (`beam_diameter_mm`) bores the rest of the
  way in. The disc is retained inward by that lip and outward by the cube wall —
  the same scheme as the reference (Ø25.4 filter, Ø22.6 clear, 1.4 mm lip).
- **Dichroic (centre).** Stood upright and tilted `fold_deg`, it sits in a slot
  the beam bores open into. It drops in from the split plane when the clamshell
  is open.
- **Alignment pins.** Three corner pins register the two halves — Ø2 dowels as
  in the reference (`DIN 7 - 2 m6`), or printed boss/socket pairs.

## 5. Verification

`check_inserts.py` builds several parameter sets and asserts, in the mesh/BREP
domain, the things that would bite on the bench:

- each half is exactly **one solid** (prints as one piece), and the two halves
  do not overlap (they meet cleanly on the split plane);
- every optic **drops into its seat** without touching the holder, an oversized
  copy interferes (a fit, not a cavern), and each **lifts out of the split
  plane** (nothing obstructs it);
- **every beam leg is bored** — a ray of the beam radius along the excitation,
  sample, emission and reflected directions meets no material;
- the alignment **pins register** — a pin passes clear through both halves.

It also checks a mixed-shape set (square excitation, round emission, round
dichroic) and the three refusals above. Run it:

```bash
uv run --with cadquery python check_inserts.py
```

## 6. Command line and wizard

```bash
# the reference set, straight from the module
uv run --with cadquery python uc2v4/beamsplitter_insert.py

# any combination, via the package CLI
uc2cad beamsplitter --exc-diam 25.4 --exc-thick 4 \
                    --emi-diam 25.4 --emi-thick 4 \
                    --dic-w 25 --dic-thick 1 --beam 18

# a rectangular excitation filter, no dichroic (two plain filter ports)
uc2cad beamsplitter --exc-w 20 --exc-h 20 --exc-thick 2 --emi-diam 25 --emi-thick 3.5
```

Each run writes `*_lower.step/.stl`, `*_upper.step/.stl` and a `*_plan.json`.

For a no-command-line path, `uc2cad wizard` (or `python -m uc2v4.wizard`) opens
a browser page where you enter the numbers for a **lens holder** or a
**beamsplitter cube** and download a ZIP of the printable files — generated on
the fly by this same code.

## 7. Deliberate simplifications

This is a clean parametric generator, not a 0.05 mm reconstruction of
PRT-2074/2075. It reproduces the design — clamshell, three ports, 45° dichroic,
corner pins, retained filters — but omits the reference's engraved labels,
draft angles, cosmetic fillets and the exact wavelength-specific pocketing.
The cube-facing interface (the square-insert outline and springs) is the exact
measured one, reused from [`interface.py`](uc2v4/interface.py).

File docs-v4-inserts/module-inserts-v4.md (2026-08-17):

---
title: Module Inserts V4
sidebar_label: Module inserts (V4)
description: How the V4 cube, master inserts and round inserts fit together, and how to place any optic anywhere inside a cube.
---

# Module inserts (V4)

Every optical component in openUC2 sits inside a 50 mm cube. This page
explains how it gets there: what the parts are, why there are two kinds of
master insert, and how you can put a lens (or a mirror, or a camera chip) at
*any* position inside the cube without designing a whole new mount.

No CAD knowledge is needed to read this. If you do want to generate your own
parts, there is a short section at the [end](#making-your-own-inserts).

## The idea in one picture

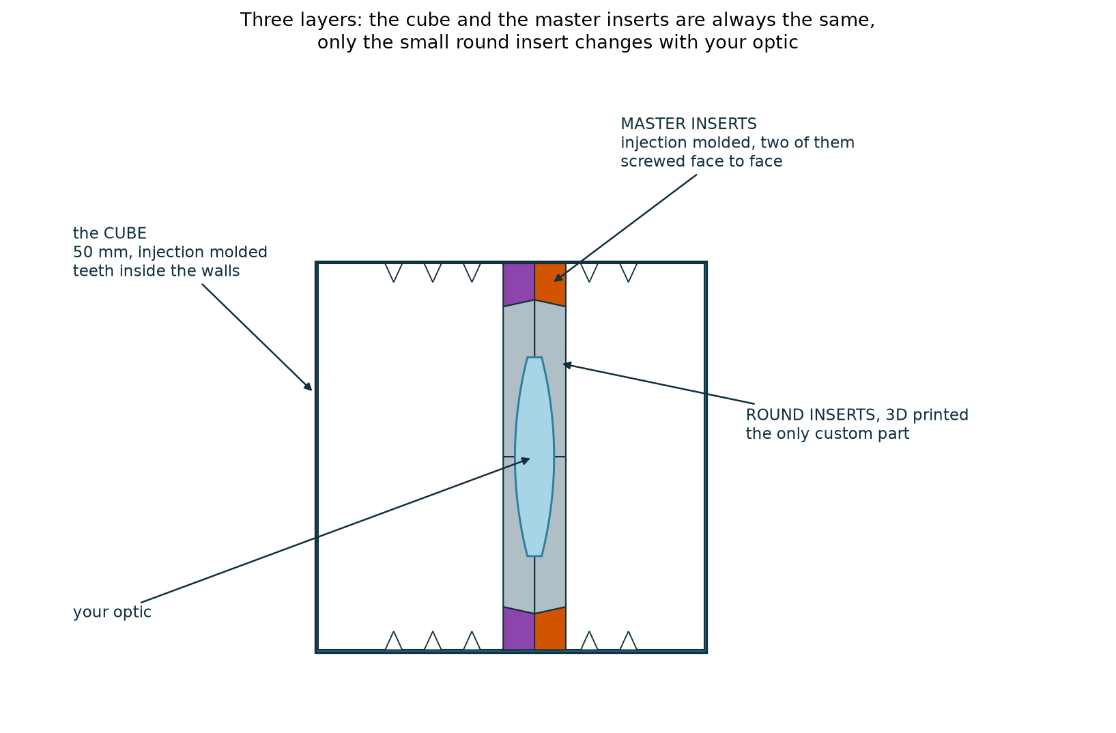
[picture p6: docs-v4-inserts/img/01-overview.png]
The three layers of a V4 module


There are three layers, and they have very different jobs:

| Layer | Made how | Changes? |
| --- | --- | --- |
| **The cube** | Injection molded | Never — it is the same for everything |
| **The master inserts** | Injection molded | Never — two standard parts |
| **The round inserts** | 3D printed | **This is the only part that changes** |

That split is the whole point. Injection molding is precise and repeatable
but a mold is expensive, so we mold only the parts that are *always* the
same. 3D printing is cheap and instant but less precise, so it only ever
handles the small custom piece in the middle — the piece that actually grips
your optic. The precision that matters, the fit into the cube, is molded.

## The cube: a ladder of teeth

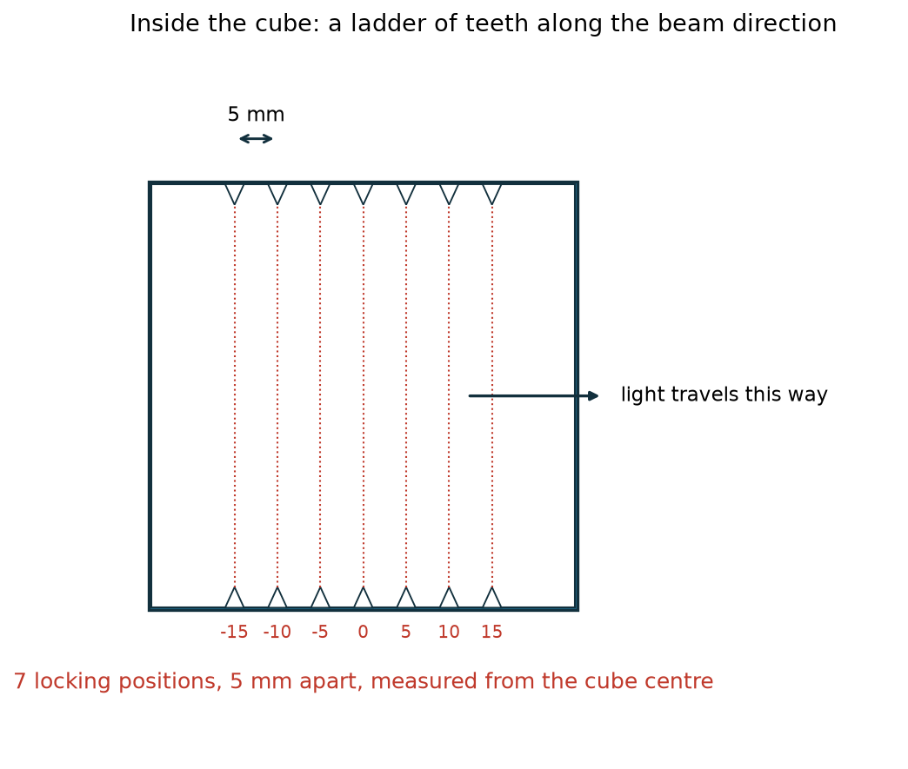
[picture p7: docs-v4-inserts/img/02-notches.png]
The notch ladder inside the cube


The cube is hollow, made from two identical molded halves. Along the inside
of two opposite walls runs a track with a row of **7 teeth, spaced exactly
5 mm apart**, sitting at −15, −10, −5, 0, +5, +10 and +15 mm measured from
the centre of the cube.

An insert slides into that track along the direction the light travels. The
teeth give it 7 defined stopping points. The *other* pair of walls has no
teeth at all — which is deliberate, and is what lets an insert be gripped in
one direction while still sliding in the other.

## The master insert: with or without nudges

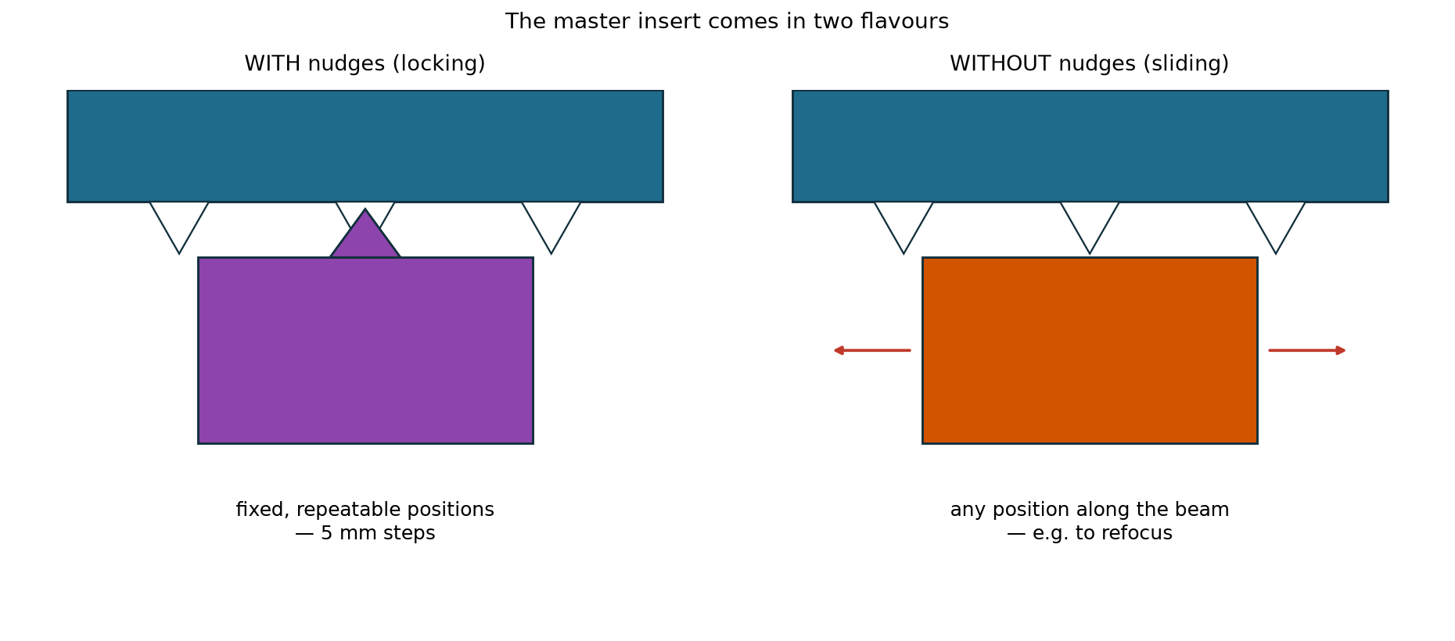
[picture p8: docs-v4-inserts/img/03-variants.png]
Locking and sliding master inserts


The master insert is a flat molded ring, 4 mm thick, that slides into the
cube. It comes in two versions:

- **With nudges** — a small bump on its edge drops into one of the teeth.
  The insert now sits at a fixed, repeatable position, and it will sit at
  exactly that same position again if you take it out and put it back. Use
  this when the position matters.
- **Without nudges** — a smooth edge. The insert slides freely along the
  track and holds by friction, so you can put it anywhere and nudge it while
  you watch the image. Use this to focus something by hand.

Apart from that edge detail the two are identical. In the middle both have
the same **round Ø40 mm opening**, and around that opening are 8 small
grooves. Those grooves are what the round insert clicks into.

## The sandwich

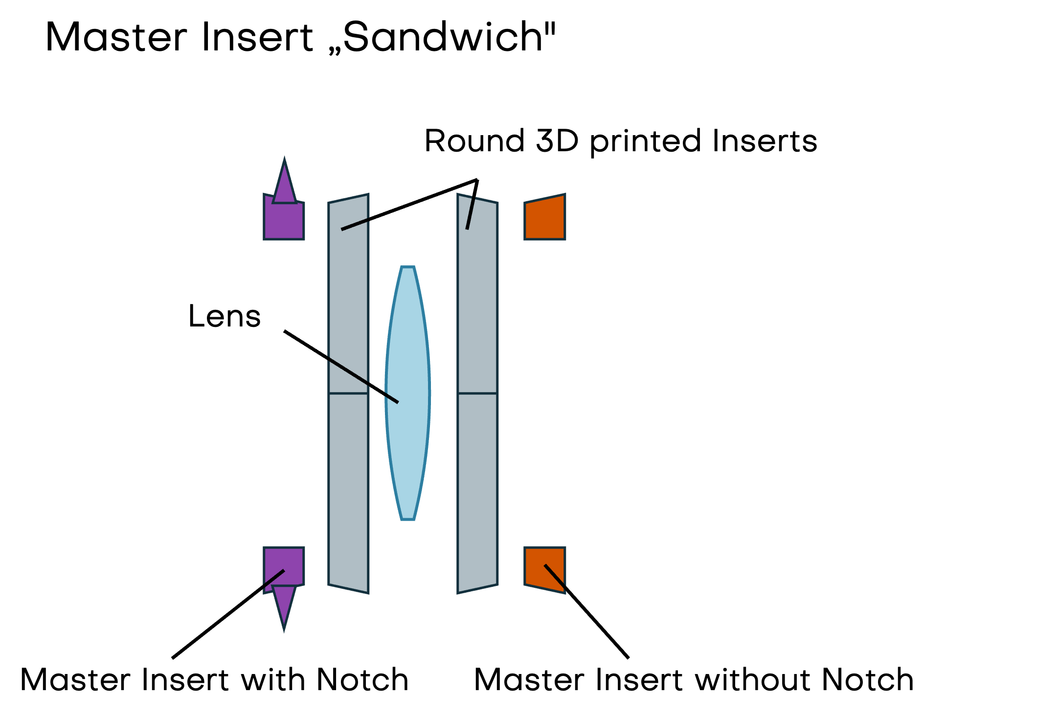
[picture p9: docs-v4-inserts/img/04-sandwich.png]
The sandwich stack


Master inserts are used **in pairs**. Two of them are screwed face to face
with two small screws (TP 2.5 × 6 Torx), and the optic is trapped between
them — sandwiched between two round inserts.

A neat detail: the two master inserts are the *same part*, just flipped. The
screw holes are arranged so that a clearance hole on one always lines up with
a thread-forming hole on the other. One mold, no left-hand and right-hand
versions, and no way to assemble it wrongly.

Because they mate flipped, both of the round openings are **widest where the
two inserts meet** and taper towards the outside. So each round insert is
dropped in from the middle and is trapped once the sandwich is closed.

## The round insert: one shape, anything inside

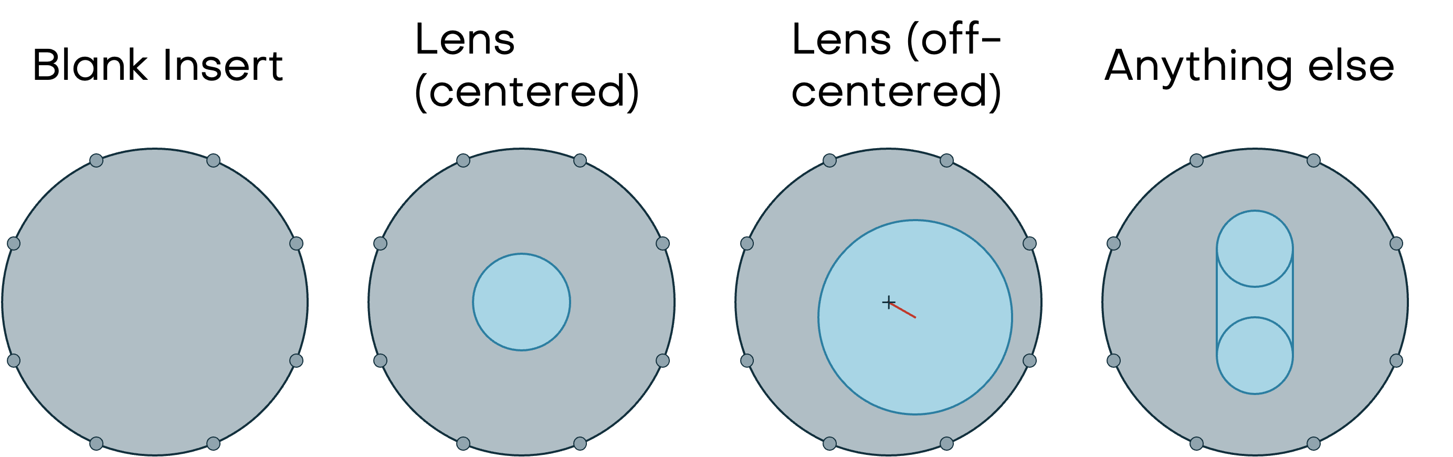
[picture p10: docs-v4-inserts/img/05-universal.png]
One disk, many optics


This is the part that makes the system flexible. The round insert is a disk
of about Ø40 mm with a ring of **8 small nubs** around its rim. Those nubs
match the grooves in the master insert, so the disk clicks in and can be
turned in **45° steps** — useful when the thing you are holding is not
rotationally symmetric, like a rectangular mirror.

The outside of that disk is always identical. What is *inside* is entirely up
to you: a hole for a small lens, an off-centre pocket for a big one, a slot
for a 45° mirror, a seat for a camera board. Everything in the catalogue —
lens holders, mirror holders, laser holders — is this same disk with a
different middle.

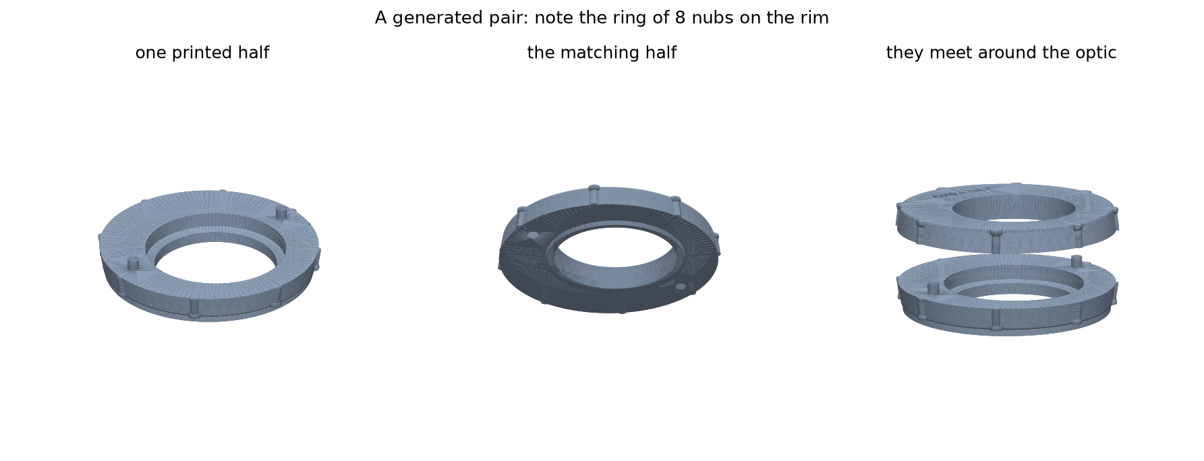
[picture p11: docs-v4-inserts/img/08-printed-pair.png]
A generated pair of printed inserts


## Placing an optic anywhere: coarse plus fine

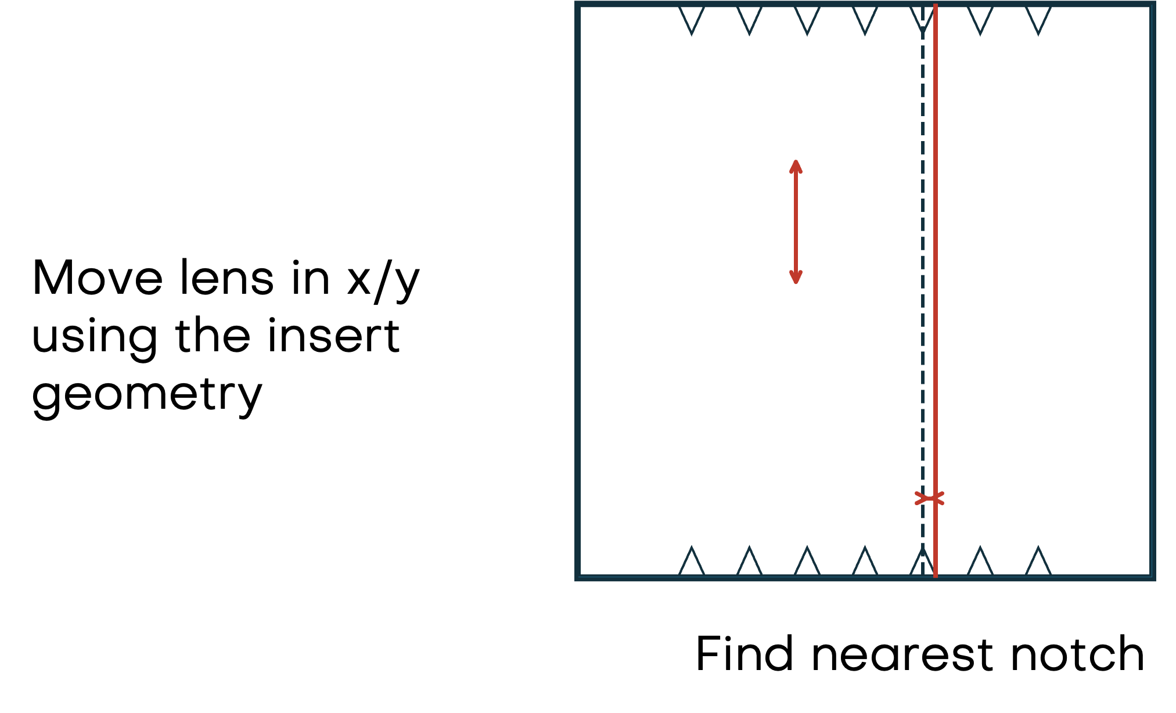
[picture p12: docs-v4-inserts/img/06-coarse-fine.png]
Coarse and fine positioning


Here is the trick that lets you reach *any* position, even though the teeth
only come every 5 mm.

The position splits into two parts:

1. **Coarse** — the cube's teeth put the sandwich at the nearest 5 mm step.
   This is molded, so it is precise and repeatable.
2. **Fine** — everything left over is simply *built into the printed insert*.
   If your lens should sit 1.1 mm past the nearest tooth, the pocket inside
   the printed part is machined 1.1 mm off-centre. The part does not move;
   the hole in it moves.

The same applies sideways. If your lens needs to sit 2 mm left and 1 mm down
from the optical axis, the pocket is simply cut 2 mm left and 1 mm down. A
tilt works the same way — the pocket is cut at an angle.

So: you specify a position, and the printed part absorbs the difference
between that position and the nearest tooth. Nothing has to be adjusted by
hand, and nothing can drift.

## Getting the optic in: seat and push ring

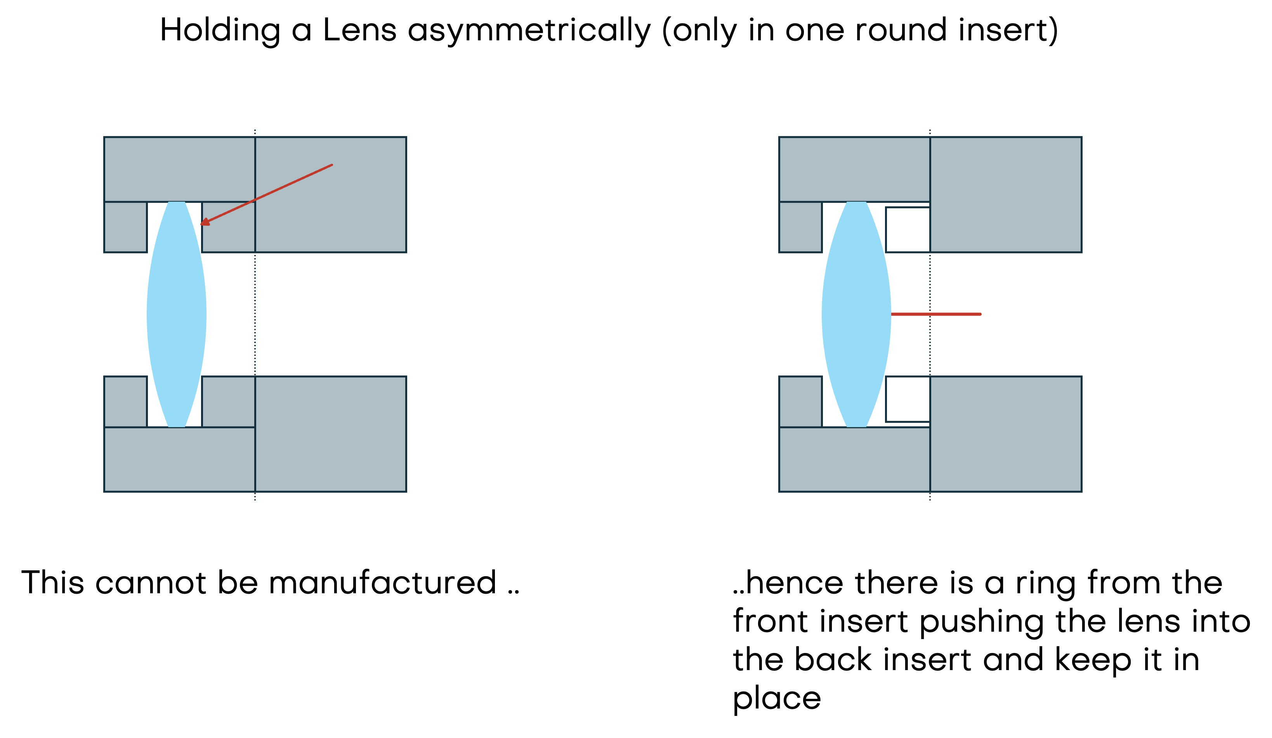
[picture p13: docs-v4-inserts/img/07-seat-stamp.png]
Why a lens can be walled in, and how to fix it


One practical wrinkle, because it is the kind of thing that only shows up
when you try to assemble the real thing.

If the optic happens to straddle the line where the two halves meet, there is
no problem: you lay it into one half and cap it with the other, like closing
a box.

But if it ends up sitting entirely *inside* one half, that half becomes a
closed pocket whose mouth is narrower than the lens — and the lens can never
be got in. The fix is:

- the half holding the optic is **bored open to the full lens diameter** all
  the way to the joint, so the lens simply drops in and comes to rest on a
  seat at the bottom;
- the other half grows a **push ring** that reaches across the joint and
  presses the lens onto that seat when the two are screwed together.

The ring only ever touches the outer edge of the optic, well outside the
clear aperture, so it never gets in the way of the light.

## Reference numbers

Handy if you are designing something that has to fit:

| | |
| --- | --- |
| Cube grid | 50 mm |
| Teeth inside the cube | 7, spaced 5.0 mm, from −15 to +15 mm |
| Insert outline | 49.4 mm square with cut corners |
| Master insert thickness | 4.0 mm (so a sandwich is 8 mm) |
| Round opening in the master insert | Ø40 mm, wall at 82° |
| Round insert | Ø ≈ 40 mm, 8 nubs, clicks every 45° |
| Sandwich screws | TP 2.5 × 6 Torx, 2 per sandwich |

## Making your own inserts

You do not need CAD to use the system — but if you want a holder for an optic
that is not in the catalogue, the round inserts can be generated
automatically from a handful of numbers.

The generator lives in
[openuc2-cadquery](https://github.com/openUC2/openuc2-cadquery) and is built
on [CadQuery](https://cadquery.readthedocs.io/) (Python). You describe the
lens and where you want it, measured from the centre of the cube:

```bash
python uc2v4/lens_cartridge.py \
  --diameter 25.4 --thickness 5 --r1 51.5 --r2 -51.5 \
  -x 2.0 -y -1.0 -z 5.3
```

and you get back:

- **two printable files** (STEP and STL) — the front and back round inserts,
  each already carrying the 8 nubs and an engraved label so you can tell them
  apart months later;
- a **summary** of what it decided: which tooth it snapped to, and how much
  offset the printed parts are absorbing;
- a **diagram** of the result, so you can check the plan before printing.

It works out the rest for you — how thick each half needs to be, whether the
optic needs the push ring described above, and whether what you asked for
actually fits. If it does not fit, it says so, rather than quietly producing
a part that cannot be assembled.

The same generator can produce the plain round blank, so it is also the
starting point for holding something that is not a lens at all.

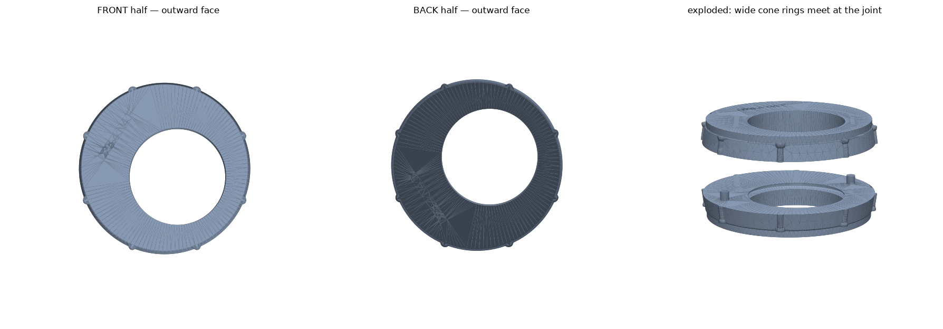
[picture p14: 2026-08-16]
generated/cartridge_labels_preview.png

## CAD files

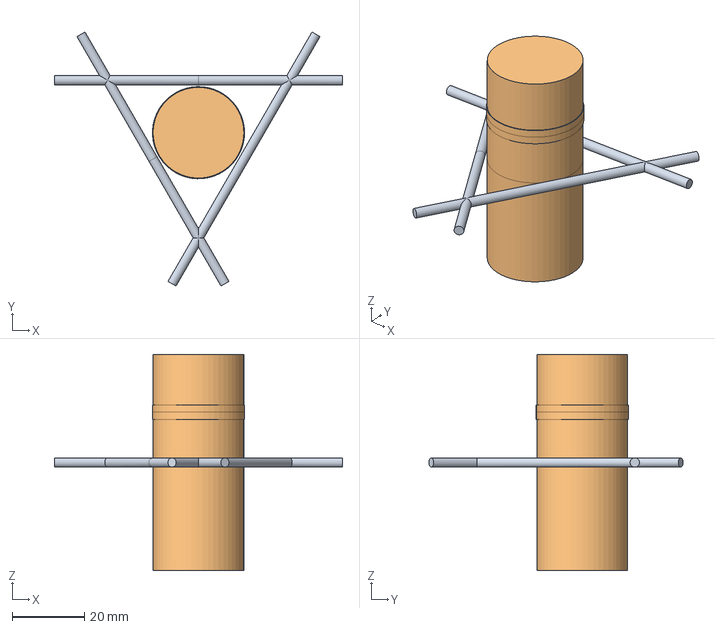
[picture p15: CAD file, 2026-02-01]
component_cut.step
80.0 x 70.6 x 60.0 mm

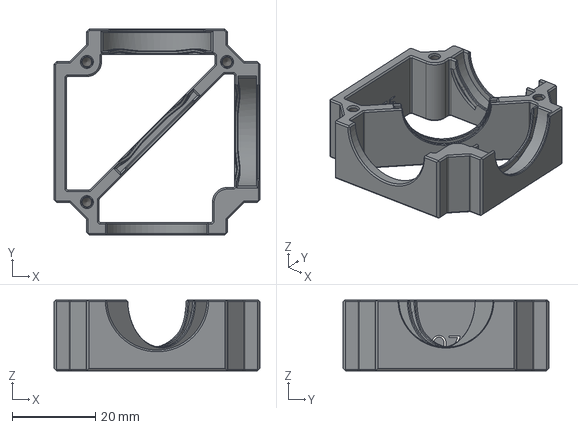
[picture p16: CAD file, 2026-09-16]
extracted/PRT_-_2075_-_LOWINSDICSPL+EMIFIL+EXCFIL_WLS485.step
49.4 x 49.4 x 17.0 mm

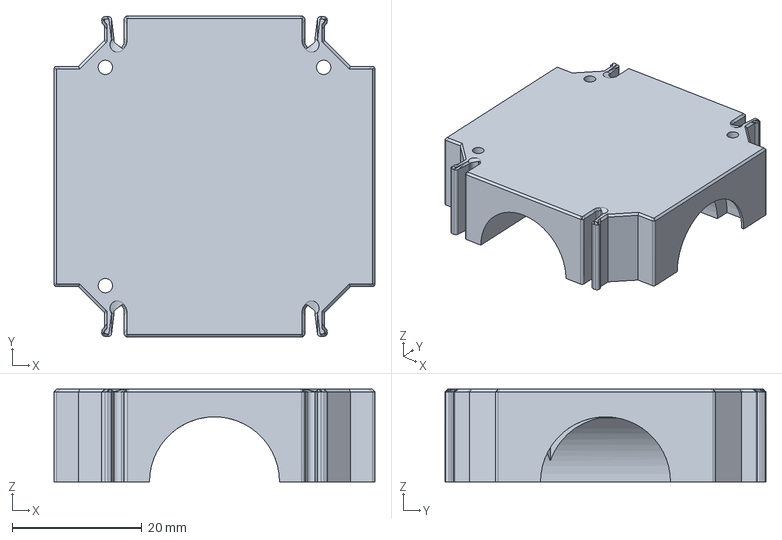
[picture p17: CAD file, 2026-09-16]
generated/beamsplitter_insert_upper.step
49.4 x 49.4 x 14.3 mm

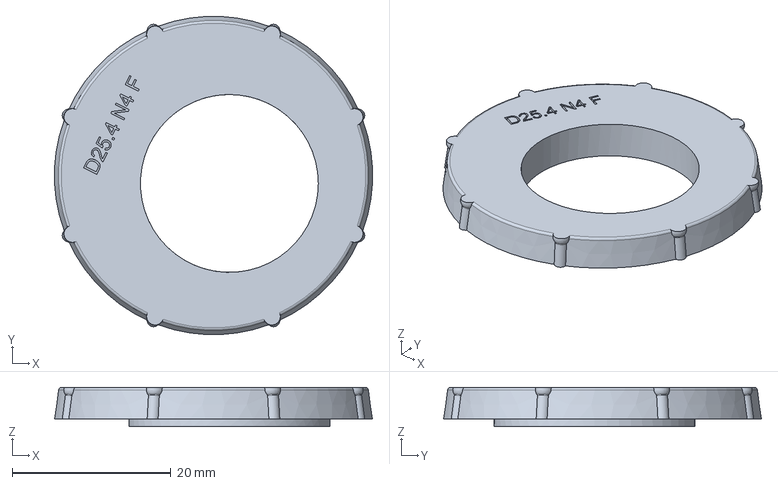
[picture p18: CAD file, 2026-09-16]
uc2v4/generated/lens_cartridge_front.step
40.0 x 40.0 x 4.92 mm

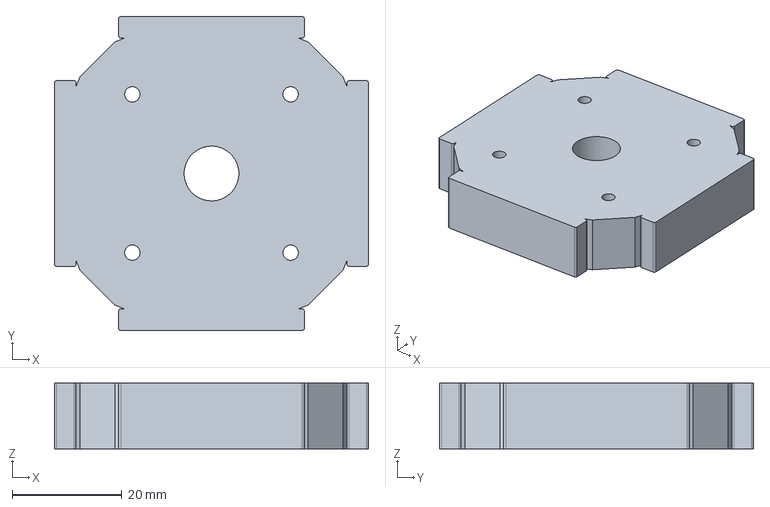
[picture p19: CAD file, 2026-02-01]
uc2_insert.step
57.3 x 57.3 x 12.0 mm

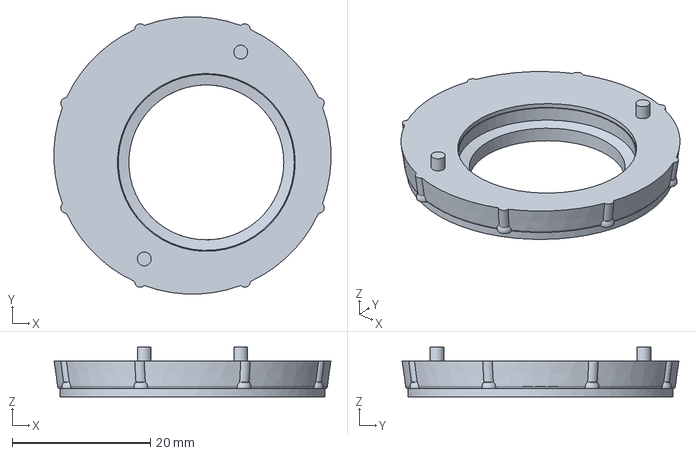
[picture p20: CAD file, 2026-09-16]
uc2v4/generated/lens_cartridge_back.step
40.0 x 40.0 x 7.20 mm

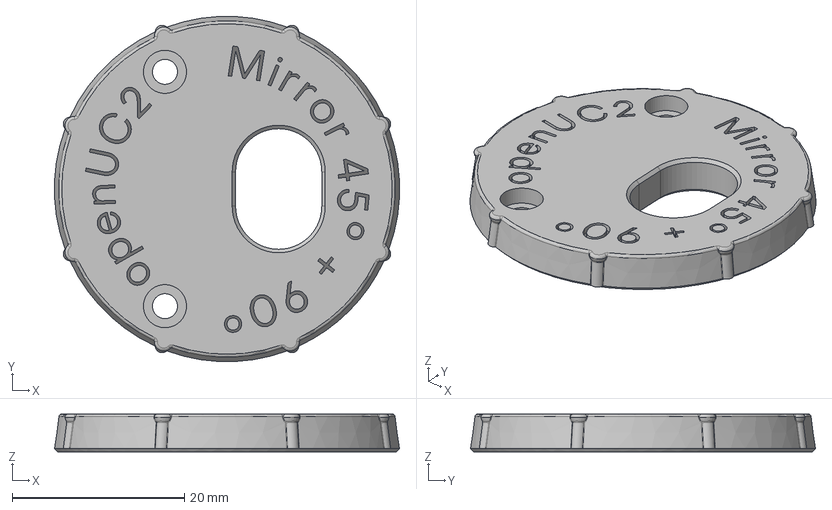
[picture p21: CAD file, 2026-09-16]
extracted/PRT_-_2111_-_MASINSMIRHOLUPP_-_C.step
40.0 x 40.0 x 4.40 mm

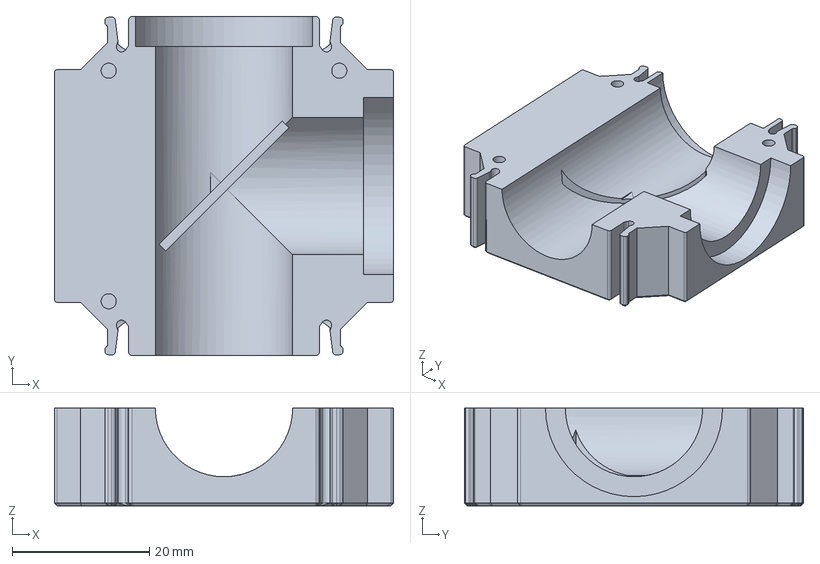
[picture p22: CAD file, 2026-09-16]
generated/uc2v4_beamsplitter_lower.step
49.4 x 49.4 x 14.3 mm

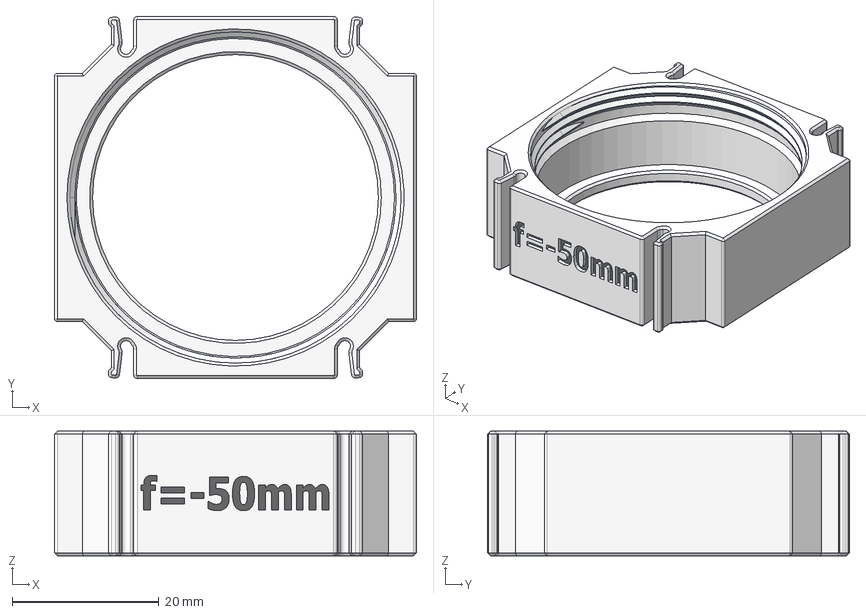
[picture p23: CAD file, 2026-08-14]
extracted/PRT_-_2027_-_INSLEND43F-50_-_V04.step
49.4 x 49.4 x 17.0 mm

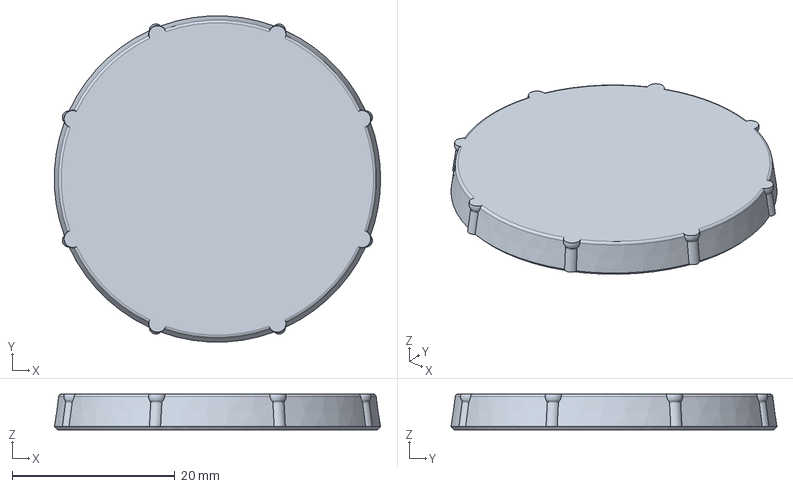
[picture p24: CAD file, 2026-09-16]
generated/uc2v4_base_holder.step
40.1 x 40.0 x 4.40 mm

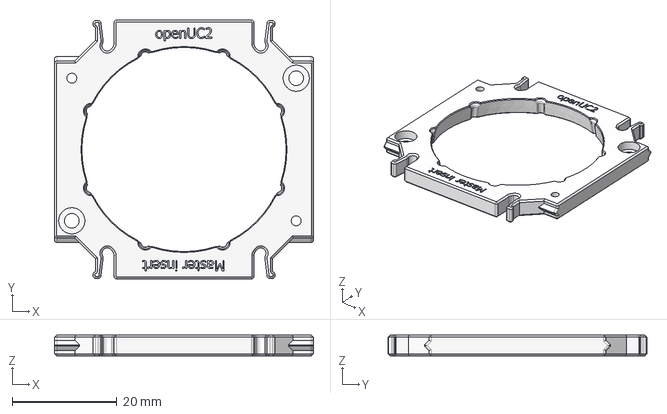
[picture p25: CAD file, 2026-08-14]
extracted/PRT_-_2123_-_MASLCK_-_V04_-_B.step
49.4 x 49.4 x 4.00 mm

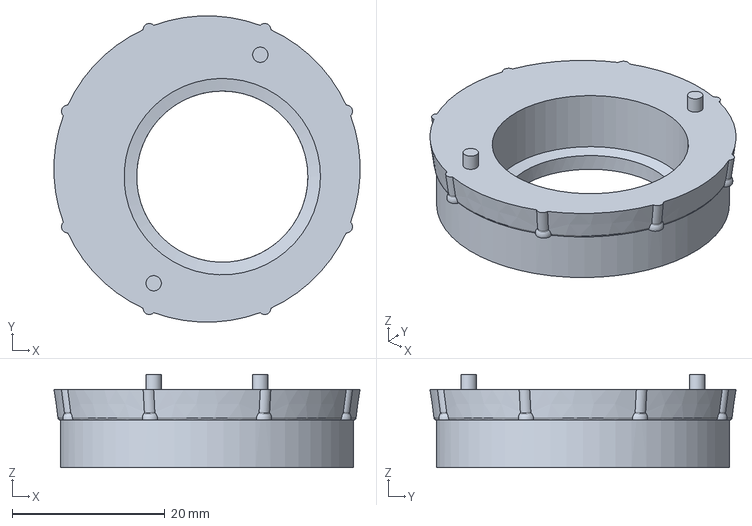
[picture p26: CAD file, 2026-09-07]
generated/lens_cartridge_back.step
40.0 x 40.0 x 12.2 mm

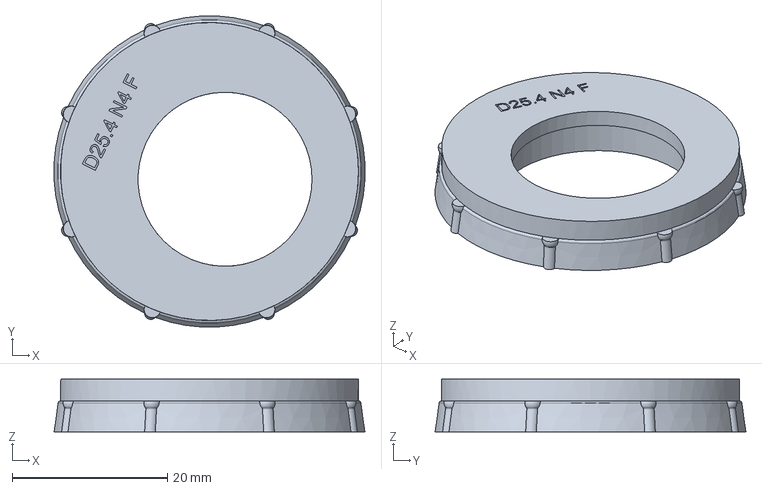
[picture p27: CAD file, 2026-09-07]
generated/lens_cartridge_front.step
40.0 x 40.0 x 6.80 mm

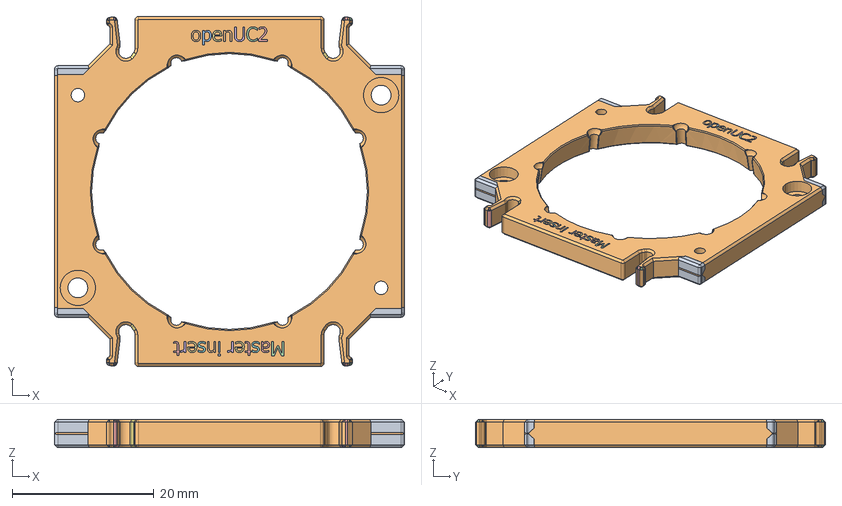
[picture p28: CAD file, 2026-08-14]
generated/uc2v4_master_insert_diff_extra.step
49.4 x 49.4 x 4.00 mm

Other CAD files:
extracted/PRT_-_2074_-_UPPINSDICSPL+EMIFIL+EXCFIL_WLS485.step
generated/beamsplitter_insert_lower.step
generated/uc2v4_beamsplitter_upper.step
generated/uc2v4_mirror_holder.step
generated/beamsplitter_insert_lower.stl
generated/beamsplitter_insert_upper.stl
generated/demo_1inch_lens_insert.step
generated/lens_cartridge_back.stl
generated/lens_cartridge_front.stl
generated/uc2_nose_conic_insert.step
generated/uc2v4_base_holder.stl
generated/uc2v4_lens_insert.step
generated/uc2v4_lens_insert.stl
generated/uc2v4_lens_insert_diff_extra.step
generated/uc2v4_lens_insert_diff_missing.step
generated/uc2v4_master_insert.step
generated/uc2v4_master_insert.stl
generated/uc2v4_master_insert_diff_missing.step
generated/uc2v4_mirror_holder.stl
uc2v4/generated/lens_cartridge_back.stl
uc2v4/generated/lens_cartridge_front.stl

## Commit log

2026-05-04 experimenting with master insert
    [uc2_nose_conic_insert.step, uc2_nose_conic_insert.stl]
2026-08-13 Add parametric UC2 V4 insert models
    Introduce a new `uc2v4` CadQuery package that reconstructs the openUC2 V4 master and lens inserts from measured Inventor data, including the shared square-insert interface, lens cavity/thread geometr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
2026-08-13 add the json and stp/stl files that were base/exported
    [PRT_-_2027_-_INSLEND43F-50_-_V04.step, PRT_-_2123_-_MASLCK_-_V04_-_B.step, demo_1inch_lens_insert.step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]
2026-08-14 performing some checks
    [uc2v4_lens_insert.step, uc2v4_lens_insert.stl, uc2v4_master_insert.stl]
2026-08-16 Add UC2 v4 round mirror holder generator
    Introduce a new `uc2v4/round_holder.py` module with parametric builders for the reusable round base holder and the 45° mirror holder geometry (aperture, noses, and screw counterbores). Add `build_mir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
2026-08-16 Add automatic lens cartridge generation
    This change adds a parametric lens-cartridge generator that takes a lens prescription and target cube pose, snaps it to the molded notch grid, and produces the front/back printed insert pair for a complete lens assembly. The generator models the lens pocket as a true offset cavity, keeps the holder inside the base-profile envelope, and emits STEP/STL plus a JSON plan. It also includes a verification harness for collision, fit, pose, and envelope checks, and updates the design notes and holder geometry to cover the expanded cartridge behavior.
2026-08-16 Add cartridge diagrams and face labels
    Generate a schematic `*_layout.png` alongside cartridge exports and engrave identifying labels on each outward face. The cartridge geometry and fit checks were updated so both halves keep the cone’s 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
2026-08-16 Add stamp mechanism for trapped lens assembly
    When a lens rim lands wholly inside one half of the cartridge, that half becomes a closed pocket — impossible to assemble. This adds automatic detection and a two-part fix:
    - The seat half is bored open to the full lens diameter from the rim face to the joint plane, allowing the lens to be dropped in.
    - The opposite half grows an annular stamp that reaches across the joint and presses the lens onto its seat.
    Also auto-sizes extension_front/back_mm (default None) to the minimum needed to bury the lens with min_wall_mm behind it. Updates the plotter, checks, docs, and CLI accordingly.
2026-09-07 integrating improvements for headless file generation
    [component_cut.stl, lens_cartridge_back.step, lens_cartridge_back.stl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]
2026-09-07 Restore the lens insert cavity, fix the CLI entry, add CI (v0.2.0)
    The lens insert had shipped as a blank plate since 2026-08-14: an if 0:
    skipped the cavity and thread, and a bare 'from interface import' broke the
    installed package. lens_cartridge.py's __main__ ignored its flags for the
    same reason. Both build scripts now fail loud when the ground truth STEP is
    missing and build without trimesh when --no-verify is passed. CI runs the
    builds, both CLIs and check_lens_cartridge.
2026-09-08 Cut the cartridge cavity from any sag profile (0.3.0)
    Surface carries radius, conic and Optiland's even-asphere terms; Lens takes
    one per face and an optional rectangular outline. Spheres stay exact arcs,
    any other face is a sampled normal offset revolved or extruded, so the
    pocket follows the glass to the print tolerance. The check script gains a
    plate, an asphere and a turned cylinder case.
2026-09-08 Fold-optic insert and SM1 adapter (0.4.0)
    fold_insert.py holds a flat plate at an angle in a 1x1 cell: the slot is the
    plate's own silhouette swept to the top face, the beam legs are bored along
    the entry, the fold and (transmissive) the far side, and the planner refuses a
    plate the cell cannot take. sm1_adapter.py threads the same blank 1.035"-40
    for the cased half of a catalog, with an optional stop shoulder. A thread form
    taller than its pitch intersects its own turns, so the depth is capped and
    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
2026-09-16 adding dichroic splitter generator
    [PRT_-_2074_-_UPPINSDICSPL+EMIFIL+EXCFIL_WLS485.step, PRT_-_2075_-_LOWINSDICSPL+EMIFIL+EXCFIL_WLS485.step, PRT_-_2111_-_MASINSMIRHOLUPP_-_C.step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]
2026-09-27 Add OPM plate generator and docs
    Adds a parametric optical-module plate generator for arbitrary layouts, including FLIM 488 and released plate validation. This change introduces the OPM plate model, CLI and wizard integration, layou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
2026-10-03 dvOPM parts: camera adapter, launch holder and bracket, sample arm
    uc2cad opm-camera / opm-launch / opm-sample build them from openuc2-opmsimulator's
    opm_layout.json. opm_detection_holder.py is the one-piece holder they replaced (kept for
    reference with its check).
2026-10-03 Holders for turning optical designs into cubes; cartridge joints within ±13 mm
    Round clamp, kinematic-mount adapter, bolt-pattern cradle, focus cartridge, off-grid plate,
    beamsplitter cube pocket, slide slot, vial and cuvette insert, cell cover: each with a plan_*
    that checks without building and a check_*.py. lens_cartridge.snap_joint places every
    master-insert pair and keeps its joint within CubeInterface.joint_limit_mm (13): at ±17 the
    outer insert sat on the cube's end frames.
2026-10-03 Turn a plate mount's leftover yaw about the part's own up axis
    off_grid_plate's docking poses put the yaw beyond the nearest quarter turn
    into offset-deg z. offset-deg turns about the part's local axes, and its
    local z lies flat (x cross up), so a feature at 132.5 deg docked its part
    tilted 42.5 deg out of the plate. The turn is about local +y, which points
    up.
2026-10-09 adding objective holder for frame
